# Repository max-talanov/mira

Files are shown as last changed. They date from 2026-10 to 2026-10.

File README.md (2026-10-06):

# MIRA

**MIRA is a research platform under development for experiments with memristor arrays and neuromorphic computing.**

The project aims to bring array control, an analog front end, digital processing, and software tools into a single system. It is intended for studying memristor readout and programming, vector–matrix multiplication (VMM), and spiking neuron models.

## Current status

**RevA** is currently in development. The repository contains two independent KiCad projects: the power schematics and an empty control project with local libraries.

Power development is focused on connection review, protection, sequencing, and monitoring. The control project is the starting point for drawing the MCU, FPGA, communications, and matrix circuits.

Schematics in this repository do not imply that the corresponding circuits have been built or validated in hardware.

## Repository contents

| Project | Current contents | Open in KiCad |
| --- | --- | --- |
| [MIRA_Power](hardware/MIRA_Power) | Power schematics, hierarchy, and local libraries | `hardware/MIRA_Power/MIRA_Power.kicad_pro` |
| [MIRA_Control](hardware/MIRA_Control) | One empty A4 schematic, an empty PCB, and local symbol, footprint, and STEP libraries | `hardware/MIRA_Control/MIRA_Control.kicad_pro` |

Each project has its own library tables and project-relative library paths. Keep its complete folder together.

The power project includes:

| File or directory | Purpose |
| --- | --- |
| `MIRA_Power.kicad_pro` | KiCad project file |
| `MIRA_Power.kicad_sch` | Top-level schematic and hierarchy navigation |
| `POWER_SYSTEM.kicad_sch` | Power system overview |
| `POWER_INPUT.kicad_sch` | Power input and primary protection |
| `PRIMARY_POWER.kicad_sch` | Primary power converters |
| `SECONDARY_POWER.kicad_sch` | Secondary power converters |
| `PROGRAM_SWITCHES.kicad_sch` | Programming voltage switching |
| `POWER_CONTROL.kicad_sch` | Power control and protection interlocks |
| `POWER_MONITOR.kicad_sch` | Voltage and current monitoring |
| `libraries/` | Local symbol, footprint, and 3D model libraries |

The power system is designed around an external **24 V DC supply**. It provides digital and analog power rails, controlled startup, rail monitoring, and fault shutdown.

## Planned architecture

- **Memristor array and analog front end:** readout, programming, and VMM operations.
- **FPGA:** array timing control and high-speed data transfer.
- **STM32:** neuron model computation and control tasks.
- **USB 3.0 and Ethernet:** communication with a host computer.
- **Mira Studio:** a desktop application for configuring experiments, controlling the device, visualizing data, and saving results.

These blocks describe the planned development direction. Their implementation status is reflected in the current project files.

## Opening the projects

1. Clone the repository:

   ```bash
   git clone https://github.com/max-talanov/mira.git
   ```

2. Open the required `.kicad_pro` file from the table above. On Linux:

   ```bash
   cd mira
   kicad hardware/MIRA_Power/MIRA_Power.kicad_pro
   # Or open the control project:
   kicad hardware/MIRA_Control/MIRA_Control.kicad_pro
   ```

3. In `MIRA_Power`, use the schematic hierarchy to navigate between blocks. In `MIRA_Control`, start with the empty A4 sheet and add circuits as development progresses.

Keep the directory structure intact. The `sym-lib-table` and `fp-lib-table` files are stored alongside the project and reference its local libraries.

## Versioning

**RevA** identifies the hardware revision. Git tags such as `v0.1.0` mark development milestones in the repository history.

| Tag | Milestone |
| --- | --- |
| `v0.1.0` | Initial KiCad project and local library import |
| `v0.2.0` | Separate Power and empty Control projects, with updated repository documentation |

Use commits for routine edits and annotated tags for milestones. Keep published tags on their original commits. A new repository tag does not change the hardware revision or indicate completed hardware validation.

See [CHANGELOG.md](CHANGELOG.md), the [commit history](https://github.com/max-talanov/mira/commits/main), and the [tag list](https://github.com/max-talanov/mira/tags).

## Licenses and attribution

See [LICENSE](LICENSE) and the third-party library and model notices included under each project's `libraries/` directory. Keep those notices with the corresponding assets.

## Next steps

- Verify electrical connections and coordinate protection thresholds with load requirements.
- Draw and review the control and matrix circuits in `MIRA_Control`.
- Complete consistent schematic formatting and descriptions.
- Review component suitability and availability.
- Prepare component placement and PCB routing.

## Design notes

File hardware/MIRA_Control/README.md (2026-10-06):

# MIRA Control — empty KiCad project

Open **MIRA_Control.kicad_pro**. The project contains one blank A4 schematic and an empty PCB. It is intended for building MIRA Control Rev.A from scratch.

## Local library

Keep the complete folder together. Both library tables use the nickname `MIRA_RevA` and project-relative paths. No global library installation is required.

- 151 unique symbols: the original ICs, connectors and passive variants, plus 16 ready-to-place 0201 capacitor/resistor variants with Value, MPN, Manufacturer, Footprint, Datasheet and Description filled in. One identical 10k resistor entry was removed.
- 48 local footprints and 48 local STEP models, including C/R 0201.
- 0201 body size is 0.6 x 0.3 mm; local copper-pad gap is 0.22 mm.
- The generic Capacitor and Resistor symbols remain generic; select the appropriate filled variant when an ordering part is known. Larger and precision variants are retained for suitable circuits.

`docs/PASSIVES_0201.csv` lists the 16 new 0201 choices. The 100n 16V part is X7S; retain the original X7R/other suitable variant when capacitance tolerance is important, including USB coupling. `docs/models/` contains model source and license records.

## Project settings

Minimum copper clearance and Default netclass clearance are 0.2 mm. Existing generic board defaults are retained; no finished layer stack, outline, net assignments or circuit is defined.

## Repository placement

Place the complete **MIRA_Control/** folder under **hardware/** in the existing MIRA repository. Commit the .kicad_pro, .kicad_sch, .kicad_pcb, both library tables, libraries/ and docs/ together. The included .gitignore excludes local preferences, locks, autosave and backup files.

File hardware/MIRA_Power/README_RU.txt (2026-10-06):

MIRA — пустой проект с готовыми библиотеками
=====================================================

Начало работы
1. Распакуйте ВЕСЬ архив в отдельную папку.
2. В менеджере KiCad откройте MIRA.kicad_pro.
3. Откройте пустую схему MIRA.kicad_sch из менеджера проекта.
4. В другом окне откройте исходный MIRA_RevA_Annotated.
5. Копируйте нужные компоненты вместе с проводами, метками и пояснениями
   через Ctrl+C и Ctrl+V в новый проект. Создавайте дочерние листы по мере
   необходимости. Для сохранения или изменения обозначений используйте
   Edit > Paste Special (Ctrl+Shift+V) и выбирайте нужный вариант аннотации.

Состав
- Пустая схема и пустая плата, проект MIRA.
- Полная библиотека MIRA_RevA из последнего Annotated: символы,
  47 посадочных мест и все поставлявшиеся с проектом локальные 3D-модели.
- Локальные полные библиотеки Device, power и Jumper. Семь используемых
  стандартных символов совпадают с их определениями в исходной схеме.
- Готовые sym-lib-table и fp-lib-table, пути относительно папки проекта.
- Настройки черчения, ERC, классов цепей и сетки соединений исходного проекта.

Не требуется добавлять библиотеку вручную или менять глобальные настройки
KiCad. Имя библиотеки MIRA_RevA сохранено, чтобы ссылки вставленных символов
и посадочных мест продолжали работать. Новый проект использует собственную
копию библиотеки: изменения в ней не изменяют исходный Annotated.

Важные детали переноса
- Не переносите только файл .kicad_pro: папка libraries и обе таблицы должны
  оставаться рядом с ним. Саму папку проекта можно перемещать целиком.
- Для монтажа электрических соединений выбирайте в редакторе сетку 50 mil
  (1.27 мм). Настройка сетки соединений уже такая; текущая отображаемая сетка
  редактора относится к личным настройкам KiCad.
- Новый лист достаточно широкий, чтобы вставить целый лист Annotated
  вместе с правой панелью описания. Формат можно изменить в Page Settings.
- Когда копируете только содержимое листа, выделяйте именно компоненты,
  провода и текст на нём. Копирование рамки дочернего листа на обзорной схеме
  переносит ссылку на файл листа: сам этот файл также нужен новому проекту.
- Стандартные 3D-модели нескольких 0603 посадочных мест используют пакет
  3D-моделей KiCad, как в исходном Annotated. На символы и вставку схем
  это не влияет.

Формат проекта: KiCad 10, как в последнем MIRA_RevA_Annotated.
Проверка: все использованные в исходных 46 листах символы и посадочные места
разрешаются в подключённых библиотеках; проект не содержит старой иерархии,
обозначений компонентов, замков или состояния навигации.

Справка KiCad:
https://docs.kicad.org/10.0/en/eeschema/eeschema.html

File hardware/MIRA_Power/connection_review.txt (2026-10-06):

MIRA Rev.A — Power Control connection review
2026-10-05

Scope and validation

Reviewed POWER_CONTROL and all ten attached child schematics, 2400 through
3300. The electrical graph was reconstructed from native embedded symbol
pins, wires, junctions, scoped local labels and global labels. KiCad instance
rotation and screen-axis mirroring were included. Manufacturer pinouts and
logic functions were checked against the documents listed below.

Four confirmed connection defects were corrected. A separate final comparison
verified every original pin position, symbol orientation, pin identity and net
partition against the source plus the four explicit repairs. The parent UUID,
all ten child sheet UUIDs, filenames and hierarchy paths were preserved.
The existing MIRA_RevA embedded definitions were retained. R3203 reuses the
existing Panasonic 10 kOhm resistor definition and footprint.

The English guides use the same five headings on every child sheet. The parent
has an individual description of every block and a logical interconnection
overview. Blue annotations distinguish circuit groups. The parent graphics
show signal relationships; the leaf global nets provide the actual electrical
connections. Preview images are approximate renders of native geometry rather
than KiCad plots. All eleven previews were visually inspected and annotations
checked against their drawing frames.

Native KiCad ERC, simulation, firmware validation, PCB checks and bench tests
were not performed. Missing monitor circuits limit whole-system conclusions.

Confirmed defects and completed repairs

1. 2600: U2601 pin 8 (global protection AND output) was unconnected, as was
   U2603 pin 1 (global permit asynchronous clear). Added the local
   GLOBAL_CLEAR_N connection between them. A LOW protection condition now
   reaches the global latch clear instead of leaving that input floating.

2. 2600: U2602 pin 8 (matrix readiness AND output) and U2603 pin 13 (matrix
   permit asynchronous clear) were unconnected. Added MATRIX_CLEAR_N between
   them. These local labels are on one sheet and do not change other nets.

3. 3100: U3103 pin 6 was globally labeled ALL_RAILS_PG. This joined it to
   the push-pull U3018 pin 6 output on 3000 and left the existing
   ALL_COMMANDS_ON input on U2602 pin 4 without its intended driver.
   Renamed the 3100 output to ALL_COMMANDS_ON. Its four local groups were
   renamed CMD_GROUP_0 through CMD_GROUP_3 and the copied hidden logic
   metadata was updated to match the actual CMD inputs.

4. 3200: U3201 pin 2 is open collector, but OC_OK_N had no external pull-up
   in any available schematic. Added R3203 = 10 kOhm from OC_OK_N to AON.
   At AON = 3.28 V its approximate fault sink current is 0.328 mA. The
   comparator output, resistor branch and global label share one continuous
   wire with a visible junction. A firmware-selected internal pull-up is not
   required to establish the released hardware level during MCU reset.

Documentation correction: J2502 now reads HOST MANUAL RESET CONTACT because
it connects to the host supervisor MR input. Its electrical pins did not move.
Several label/field positions were adjusted solely for legibility.

Verified circuit relationships

2400 — Dedicated power sequencer
U2401 is STM32G0B1RBT6, GP LQFP64. Its embedded supply and GPIO pin mapping
matches the GP part, including PD8/PD9 at pins 40/41. USART3 AF0 can use
these UART pins. PA0/PA1/PA2/PA3 receive ADC_I/ADC_V/ADC_VTT/PROG_V_P15.
Permits and externally driven status signals must be firmware inputs; enable,
arm and kill requests must initialize safely. Use internal clocking because
PF0 drives EN_REQ_USB. Keep NRST and SWD enabled and VREFBUF disabled while
VREF+ is tied to AON. FPGA matrix timing and STM32H745 neuron computation
remain outside this power sequencer.

2500 — Independent supervision
U2501 uses AON; U2502 uses SYS3V3. Both have SET1 HIGH and CWD unconnected:
watchdog timeout is 1.60 s nominal (1.36–1.84 s specified). Falling WDI edges
service the timers. Reset release delay and WDO LOW pulse are 200 ms nominal.
D2501 common-anode BAT54A correctly combines AON_RESET_N and PM_WDO_N into
PM_RESET_N. No diode rotation was needed. Host watchdog expiry inhibits the
matrix but does not locally combine WDO into the host RESET output.

2600 — Hardware permission and fault memory
The restored clear chains implement these conditions (AND of every item):

GLOBAL_CLEAR_N:
  AON_RESET_N, PM_WDO_N, PG_INPUT, FLT_INPUT_N, OC_OK_N,
  global stop/kill healthy node, PM_RESET_N.

MATRIX_CLEAR_N:
  GLOBAL_PWR_PERMIT, ALL_RAILS_PG, ALL_COMMANDS_ON, HOST_WDO_N,
  HOST_RESET_N, matrix stop/kill healthy node.

U2603 D inputs are HIGH and presets inactive. A rising arm edge can set a
permit only while its clear is HIGH. Any LOW clear asynchronously removes
that permit. Recovery alone does not re-arm. A global fault also removes the
matrix condition. Stops are CLOSE TO TRIP; an open cable is not detected.
Startup AON reset and clean arm timing still require system verification.

2700 / 2800 — Fifteen qualified enable commands
All eight primary and seven auxiliary channels use:
  CMD_x = EN_REQ_x AND GLOBAL_PWR_PERMIT.
Request and command pull-downs are present. The auxiliary spare gate has
grounded inputs and an NC output. Clearing the global permit suppresses all
commands independently of requests. Converter shutdown and discharge times
belong to their connected rail circuits.

2900 — Four analog readiness channels
Outputs PG_USB, PG_ANA, PG_P15 and PG_N15 have 10 kOhm AON pull-ups.
For AON = 3.28 V, the reference thresholds at the MON inputs are:
  MON_V_USB:   2.2313 V
  MON_V_ANA6:  2.6885 V
  MON_V_P15:   2.3597 V
  MON_V_N15:   1.3120 V
C2901–C2904 filter REFERENCES, with nominal time constants approximately
32, 18, 28 and 60 us. They do not filter the MON inputs or specify a fixed
power-good qualification delay. No analog feedback hysteresis is drawn.
Actual rail thresholds require the missing monitor scaling and polarity.

3000 / 3100 — Separate readiness and command aggregates
3000 ANDs fifteen measured PG/PGR signals into ALL_RAILS_PG.
3100 ANDs fifteen qualified CMD signals into ALL_COMMANDS_ON.
Each corrected global has one explicit push-pull driver. The local group
labels on the two sheets are independent. Global startup permission does
not depend on switched-rail readiness, allowing startup without a logical
deadlock. Matrix permission requires both aggregates; intentionally disabling
any included rail prevents matrix authorization. Neither tree contains a
timer or latch.

3200 — Negative-current check
Reference = AON x 10 / 57 = 0.57544 V at AON = 3.28 V.
C3201 filters this reference; (47 kOhm || 10 kOhm) x 10 nF = 82.46 us.
OC_I_N15 above the reference pulls OC_OK_N LOW and clears the global permit.
The conditioned current-sense producer is missing from the supplied scope,
so a trip current in amperes cannot be calculated or validated.

3300 — Debug and host interface
J3301: 1 AON reference, 2 GND, 3 SWDIO, 4 SWCLK, 5 PM_RESET_N.
J3302: 1 SYS3V3 reference, 2/9/10 GND, 3 buffered PM UART TX,
4 HOST_UART_TX, 5 HOST_WDI, 6 buffered MATRIX_PERMIT,
7 buffered ALL_RAILS_PG, 8 buffered GLOBAL_PWR_PERMIT.
HOST_RESET_N is not on J3302. U3301 supplies the four host-facing outputs
from SYS3V3 and supports partial power down. Host receive is pulled LOW
when undriven; firmware must handle this UART break/off condition.
R3304/C3301 form the nominal 10 us VTT ADC filter, with BAT54S rail clamps.

Remaining integration checks

- No producer for OC_I_N15 or MON_V_USB/ANA6/P15/N15 exists in the available
  native schematics. Do not attach raw negative voltage to the AON inputs.
  Restore or supply the documented conditioning circuits before relying on
  these protections. Current gain/offset and real rail thresholds are unknown.
- ADC_I/ADC_V and the telemetry multiplexer continue to unprovided circuitry.
  The available file named 1200_POWER_MONITOR contains a CORE regulator,
  not the required monitor/multiplexer. Do not infer its function from its name.
- SYS3V3 does have a producer on the earlier 700_SYS_3V3 sheet. The host
  supervisor output below its POR level is undefined; AON pull-ups can make
  off-rail status look HIGH. Independent measured readiness must inhibit arm.
- Confirm the external host supplies HOST_WDI and receives reset through a
  separately defined path. Verify firmware recovery policy for host expiry.
- Verify all fifteen rails are intentionally required for matrix operations,
  ADC input settling and clamp injection, reset LOW margins, AON startup,
  comparator noise, arm/clear timing and actual shutdown on hardware.

Manufacturer references

ST STM32G0B1 GP pinout and alternate functions:
https://www.st.com/resource/en/datasheet/stm32g0b1ve.pdf
TI TPS3851 pinout, output behavior and watchdog settings:
https://www.ti.com/lit/ds/symlink/tps3851.pdf
TI SN74HC74 clear/preset and latch behavior:
https://www.ti.com/lit/ds/symlink/sn74hc74.pdf
TI SN74HCS21 AND gates and Schmitt inputs:
https://www.ti.com/lit/ds/symlink/sn74hcs21.pdf
TI TLV1704 comparator pinout and output pull-up requirement:
https://www.ti.com/lit/ds/symlink/tlv1704.pdf
Nexperia 74LVC125A buffering and partial power down:
https://assets.nexperia.com/documents/data-sheet/74LVC125A.pdf

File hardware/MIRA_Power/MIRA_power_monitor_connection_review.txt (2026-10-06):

MIRA Rev.A — Power Monitor connection review
2026-10-05

Scope and validation

Reviewed POWER_MONITOR and its seven active child sheets, 3400 through 4000.
Connections were reconstructed from the native embedded symbol definitions,
rotation/mirror-aware pin geometry, wires, junctions and scoped labels. The
monitor signals were traced through the previously reviewed rail, programming
and Power Control sheets. Manufacturer pinouts and functions were checked.

An independent final comparison verified 242 symbol identities and all pin
positions and net partitions. Wires, labels, junctions and no-connect markers
are unchanged. The sole component change is R3609, described below. Parent and
child UUIDs, hierarchy paths, filenames and MIRA_RevA definitions are preserved.

The overall sheet contains an E4-style logical interconnection overview and
individual descriptions of all seven blocks. The graphical collector denotes
16 separate signal pairs; it is not an electrical short or a KiCad bus. Actual
connections remain the global nets in the native leaves. The leaf guides use
the same five headings. Blue notes distinguish repeated circuits. All eight
previews were visually checked and all new text fits the existing drawing
frames. Previews are approximate renders of native geometry, not KiCad plots.

The empty, unreferenced 3600_MONITOR_INPUT_AON_USB_SYS attachment shares the
3500 root UUID. It was left unchanged and excluded from the active bundle.

Native KiCad ERC, simulation, firmware/PCB validation and bench measurements
were not performed. This review confirms the stated schematic relationships,
not validated whole-system protection or shutdown timing.

Confirmed defect and completed correction

3600: R3609 = 10 kOhm and R3610 = 10 kOhm demanded MON_V_P15 = 7.5 V
at a 15 V rail, continuously loading the AON clamp and corrupting telemetry.
R3609 is now 47 kOhm. MON_V_P15 = P15 / 5.7, giving 2.6316 V at 15 V.
The native library ID, value, MPN and description now consistently identify
Panasonic ERJ1GNF4702C; the existing 0201 footprint and pin locations remain.
This scale also gives a nominal PG_P15 threshold of 13.4504 V at AON = 3.28 V.

Verified current sensing and nominal thresholds

The positive-rail INA301A1 channels have gain 20 V/V. Their 10 kOhm LIMIT
resistors set a nominal 0.800 V threshold from the nominal 80 uA source.
Grounded RESET selects transparent alerts. Current filters follow OUT and
do not delay the internal overcurrent comparator. Nominal values below omit
amplifier, limit-source, shunt, resistor and temperature errors.

Rail        External shunt       Current scale     Nominal trip
INPUT       stated 20 mOhm       0.400 V/A         no local alert
AON         R503, 100 mOhm       2.000 V/A         0.400 A
USB         R604, 50 mOhm        1.000 V/A         0.800 A
SYS         R705, 10 mOhm        0.200 V/A         4.000 A
FPGA        R805, 10 mOhm        0.200 V/A         4.000 A
ANA6        R904, 50 mOhm        1.000 V/A         0.800 A
P15         R1004, 100 mOhm      2.000 V/A         0.400 A
N15         R1107, 100 mOhm      2.000 V/A         0.288 A at AON 3.28 V
CORE        R1205, 2 mOhm        0.040 V/A        20.000 A
AUX18       R1305, 20 mOhm       0.400 V/A         2.000 A
AUX25       R1405, 20 mOhm       0.400 V/A         2.000 A
IO33        R1505, 20 mOhm       0.400 V/A         2.000 A
DDR         R1605, 10 mOhm       0.200 V/A         4.000 A
PHY         R1705, 20 mOhm       0.400 V/A         2.000 A
ANA5        R1905, 50 mOhm       1.000 V/A         0.800 A
ANA33       R2005, 50 mOhm       1.000 V/A         0.800 A

U3501 INA293 supplies input-current telemetry. Its IN+ is BUS24_PRE_SHUNT
and IN- is BUS24. The current 400_INPUT_FILTER_SENSE leaf was not supplied.
The stated 20 mOhm input shunt is corroborated by the historical input-filter
reference (R203 between those same nets), but its current reference/value and
the PG_INPUT producer still require the actual current input subsystem.
All fifteen other shunt polarities and net names match the supplied rail sheets.

3400: U3401 OPA2991 uses AON for V+ and N15_RAW for V-. Channel A gives
20 x (N15 - N15_RAW), a positive return-current signal. MON_I_N15 uses a
10 kOhm/100 nF filter; OC_I_N15 uses a separate 10 kOhm branch without that
telemetry capacitor. Channel B gives MON_V_N15 = -0.1 x N15; -15 V becomes
+1.50 V. Both telemetry time constants are nominally 1 ms. BAT54S clamp
polarities are correct. The four differential gain-network resistors specify
0.1% tolerance. Their resistor-only worst-case common-mode leakage at -15 V
is approximately +/-57 mV, or +/-28.6 mA equivalent; the complete error budget
must also include amplifier, shunt, comparator, reference and layout errors.

Voltage scales and hardware power-good

INPUT uses (75k + 75k) / 10k, giving rail/16. P15 now uses rail/5.7.
N15 uses -rail/10. All other selected voltage channels use rail/2.
The positive current filters have nominal RC = 10 us. The half-scale voltage
filters have RC = 50 us; INPUT is 93.75 us and repaired P15 is 82.46 us.

MON_V_USB, MON_V_ANA6, MON_V_P15 and MON_V_N15 directly feed the four
2900 comparator channels as well as telemetry. At AON = 3.28 V their nominal
physical rail readiness thresholds are USB 4.4626 V, ANA6 5.3770 V,
P15 13.4504 V and |N15| 13.1200 V. These follow AON and upstream ratios;
they are not precision absolute thresholds. There is no local hysteresis.

Shared overcurrent and interlocks

Fourteen INA301 open-drain ALERT outputs and the 3200 negative-current
comparator share OC_OK_N. A fault pulls it LOW and reaches the hardware permit
clear on 2600 independently of telemetry scanning. It also reaches 2400 PA12.
The 3200 reference is AON x 10/57 = 0.57544 V at 3.28 V. With the 3400
2 V/A scale, its nominal trip is 0.28772 A. The comparator reference RC is
82.46 us; this is not a specified complete fault-to-shutdown delay.

R4008 already provides 10 kOhm to AON. Retained R3203 on the reviewed Power
Control sheet adds a parallel 10 kOhm, making the assembled pullup 5 kOhm
and approximately 0.656 mA fault sink current at AON = 3.28 V. These pullups
are compatible; OC_OK_N does not depend on a firmware internal pullup.

Verified paired telemetry channel map

Both selectors use this exact order. A0 is the least significant address bit.
The pin column is the physical channel pin on each CD74HC4067.

Channel  A3..A0  Pin  Current net      Voltage net      Source sheet
      0  0000     9   MON_I_INPUT      MON_V_INPUT      3500
      1  0001     8   MON_I_AON        MON_V_AON        3500
      2  0010     7   MON_I_USB        MON_V_USB        3500
      3  0011     6   MON_I_SYS        MON_V_SYS        3500
      4  0100     5   MON_I_FPGA       MON_V_FPGA       3600
      5  0101     4   MON_I_ANA6       MON_V_ANA6       3600
      6  0110     3   MON_I_P15        MON_V_P15        3600
      7  0111     2   MON_I_N15        MON_V_N15        3400
      8  1000    23   MON_I_CORE       MON_V_CORE       3700
      9  1001    22   MON_I_AUX18      MON_V_AUX18      3700
     10  1010    21   MON_I_AUX25      MON_V_AUX25      3700
     11  1011    20   MON_I_IO33       MON_V_IO33       3700
     12  1100    19   MON_I_DDR        MON_V_DDR        3800
     13  1101    18   MON_I_PHY        MON_V_PHY        3800
     14  1110    17   MON_I_ANA5       MON_V_ANA5       3800
     15  1111    16   MON_I_ANA33      MON_V_ANA33      3800

3900: Both devices share MUX_A0..A3 and MUX_DISABLE. HIGH disconnects
both COM outputs; LOW enables the chosen current/voltage pair. R4001-R4004
hold address zero and R4007 holds disable HIGH at controller reset. Disabled
COM inputs float, so the buffer/ADC outputs are not valid measurements.

4000: U4001A follows MUX_I_COM; output pin 1 feeds back to IN- pin 2.
U4001B follows MUX_V_COM; output pin 7 feeds back to IN- pin 6. R4005/C4002
and R4006/C4003 use 100 Ohm/1 nF (0.10 us nominal RC). Feedback is taken
before these resistors. ADC_I reaches 2400 PA0/pin 17 and ADC_V PA1/pin 18.
MUX_A0/A1/A2/A3/DISABLE reach PB15/PA8/PA9/PC6/PC7 respectively.

Firmware should disable, update the address, enable and wait for the source,
selector, buffer and ADC acquisition to settle before accepting samples.
The 0.10 us output RC alone does not define this wait. Current and voltage
are a selected pair; the STM32 ADC samples them sequentially. ADC_VTT is a
separate 3300-to-PA2 route; PROG_V_P15 is a separate 2300-to-PA3 route.

Remaining design decisions and verification

- CORE nominal trip 20 A exceeds the TPS568215 8 A converter rating. DDR
  nominal trip 4 A exceeds the TPS62130A 3 A converter rating. The converters'
  own limits may act first. Establish load, inrush and thermal budgets, then
  coordinate external trips with the regulator limits; their resistor values
  were retained rather than selecting an unsupported load budget.
- ANA5 current includes its downstream ANA3V3 load. Coordinate these nested
  thresholds instead of treating them as independent available load budgets.
- Confirm the current input-filter/eFuse leaves, PG_INPUT/FLT_INPUT_N and
  input shunt identity before claiming complete startup-path validation.
- Qualify telemetry and arm logic during AON loss, rail ramp/discharge and
  negative-supply transitions. Check clamp injection and all analog input
  operating limits when adjacent supplies are absent.
- Verify Kelvin shunt routing, gain/offset calibration, comparator noise,
  safe firmware pin defaults, ADC acquisition and actual shutdown on hardware.

Manufacturer references

TI OPA2991: https://www.ti.com/lit/ds/symlink/opa2991.pdf
TI INA301: https://www.ti.com/lit/ds/symlink/ina301.pdf
TI INA293: https://www.ti.com/lit/ds/symlink/ina293.pdf
TI CD74HC4067: https://www.ti.com/lit/ds/symlink/cd74hc4067.pdf
TI TLV9002: https://www.ti.com/lit/ds/symlink/tlv9002.pdf
TI TLV1704: https://www.ti.com/lit/ds/symlink/tlv1704.pdf
TI TPS568215: https://www.ti.com/lit/ds/symlink/tps568215.pdf
TI TPS62130A: https://www.ti.com/lit/ds/symlink/tps62130a.pdf
ST STM32G0B1: https://www.st.com/resource/en/datasheet/stm32g0b1ve.pdf

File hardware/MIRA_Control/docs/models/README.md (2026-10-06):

# Local 3D models

All 48 footprints reference models through `${KIPRJMOD}/libraries/MIRA_RevA.3dshapes/`. The STEP files and source/licensing records in model_manifest.json are copied from the updated MIRA Control Rev.A library.

Six models are nominal drawing models: HD3SS3220, Micron DDR3L FBGA96, SiTime SiT9121, Winbond WSON8 and the two new 0201 passives. They are package envelopes rather than manufacturer-certified tolerance models. The two 0201 models are original CC0 geometry; earlier models retain their documented licensing.

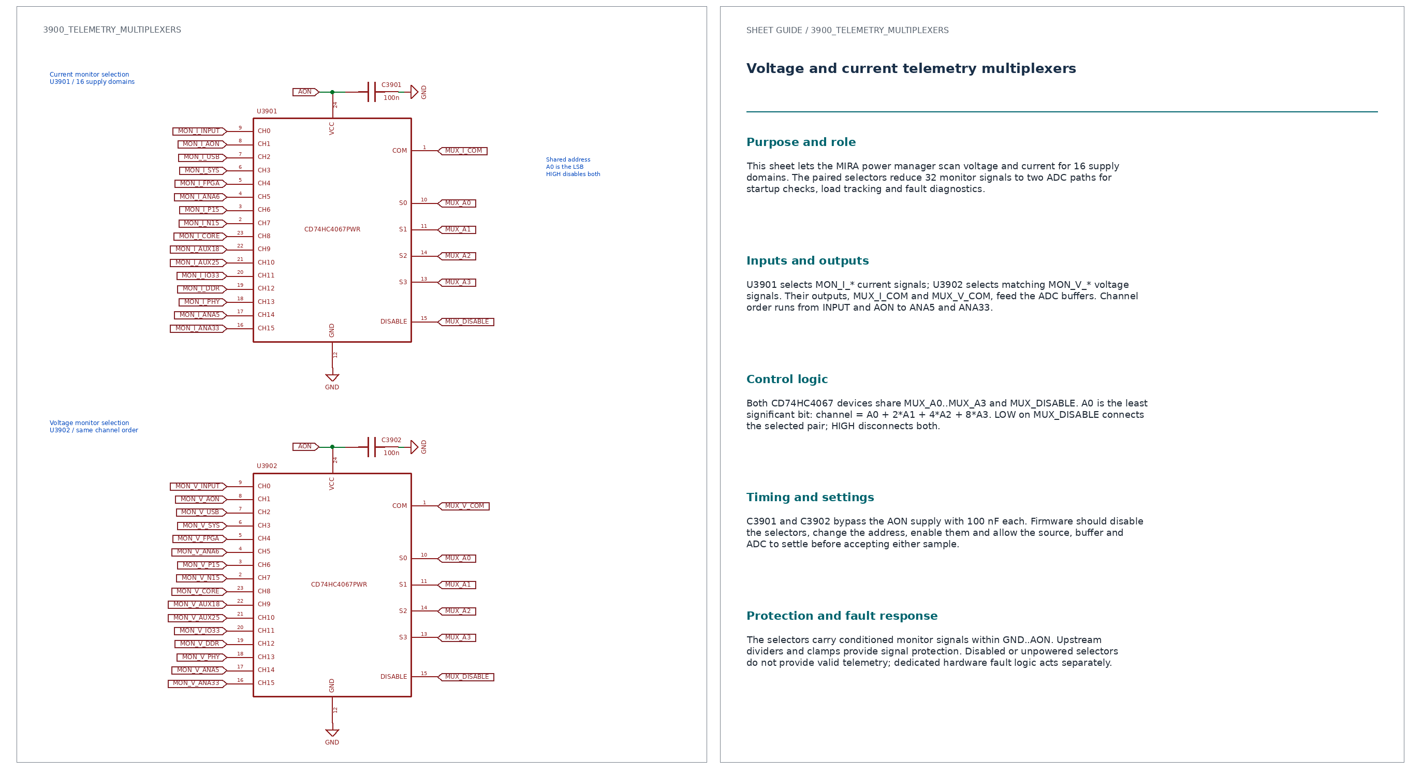
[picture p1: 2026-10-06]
hardware/MIRA_Power/3900_TELEMETRY_MULTIPLEXERS_preview.png

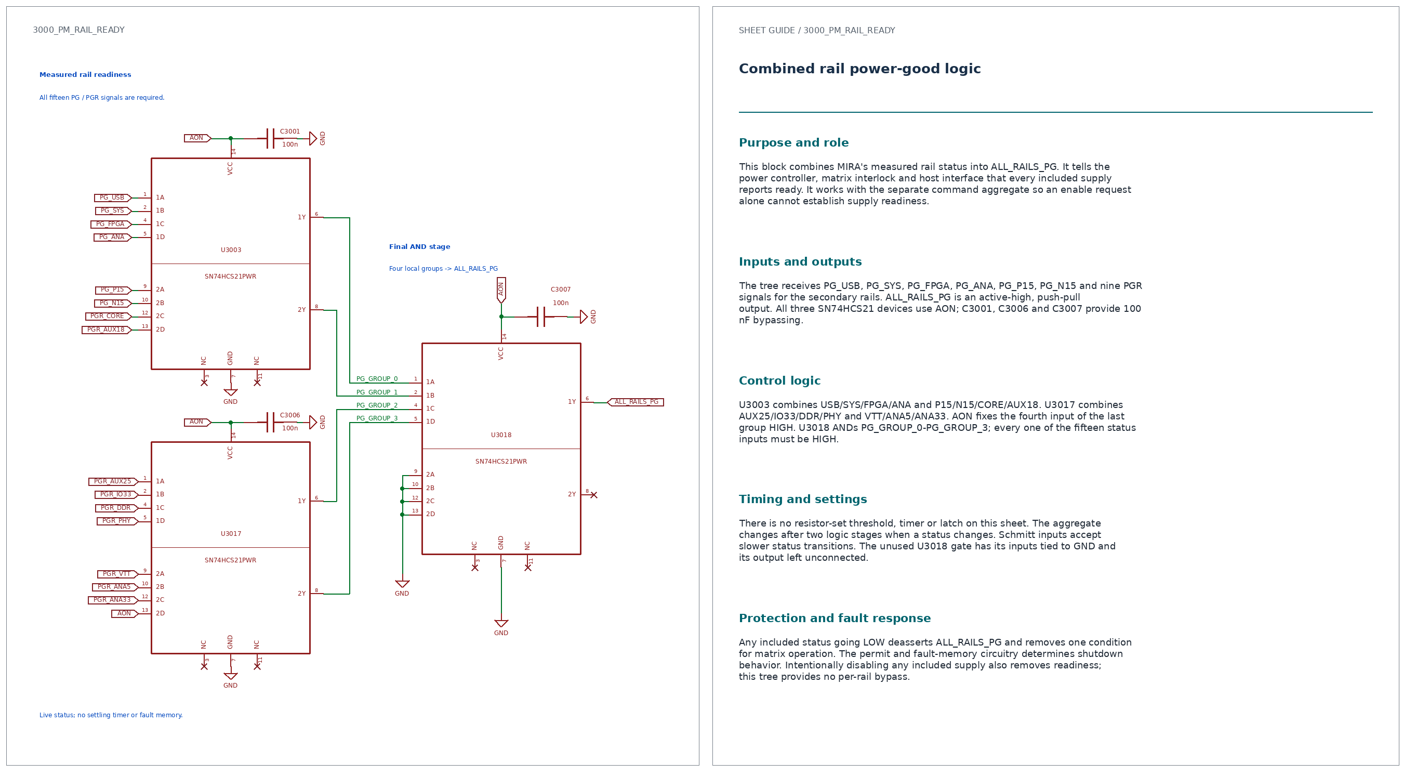
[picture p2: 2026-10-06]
hardware/MIRA_Power/3000_PM_RAIL_READY_preview.png

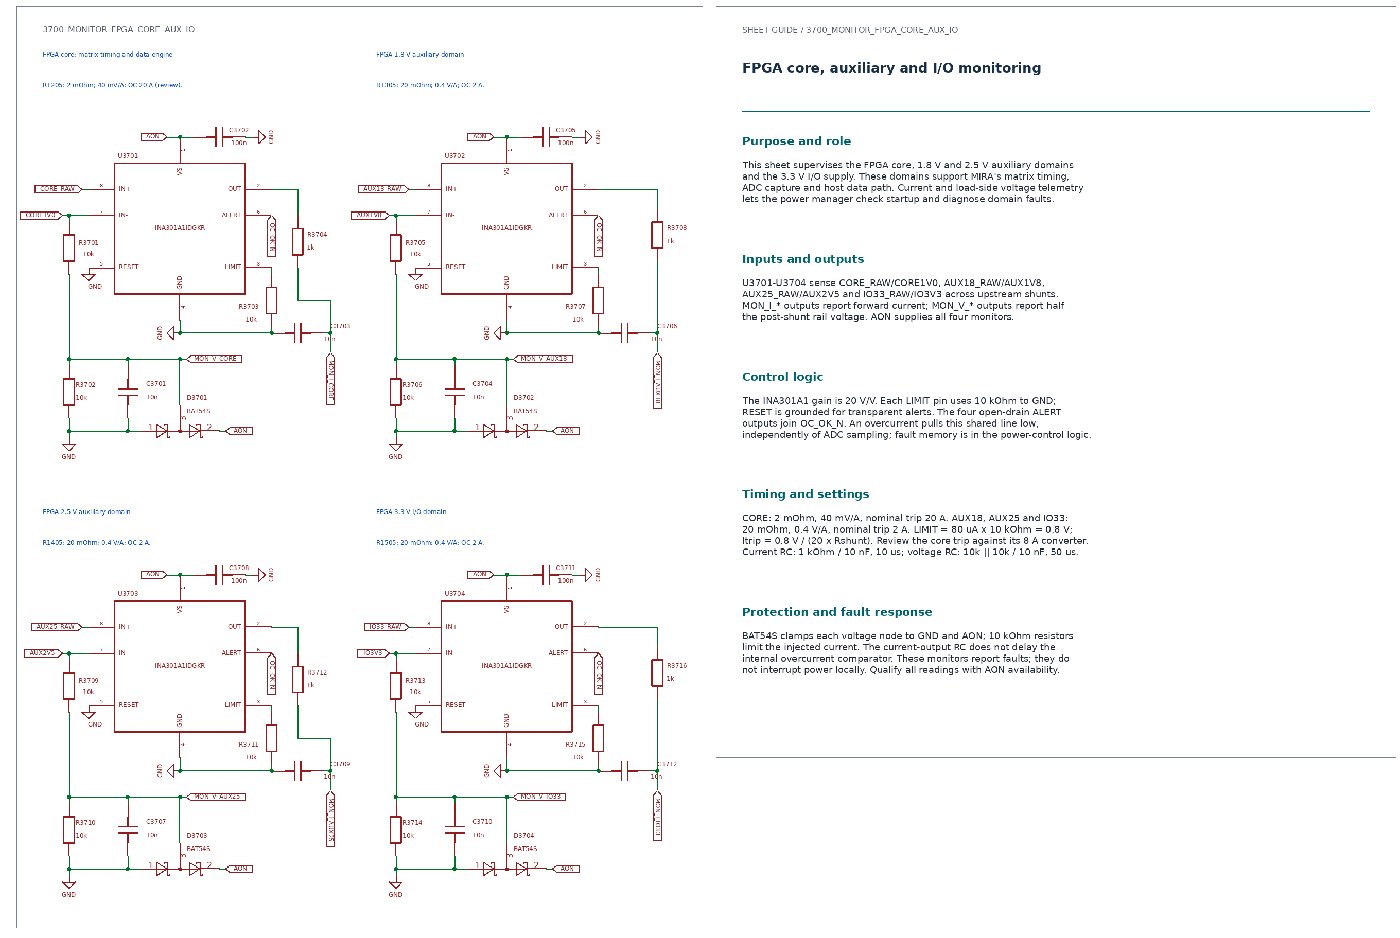
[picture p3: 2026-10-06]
hardware/MIRA_Power/3700_MONITOR_FPGA_CORE_AUX_IO_preview.png

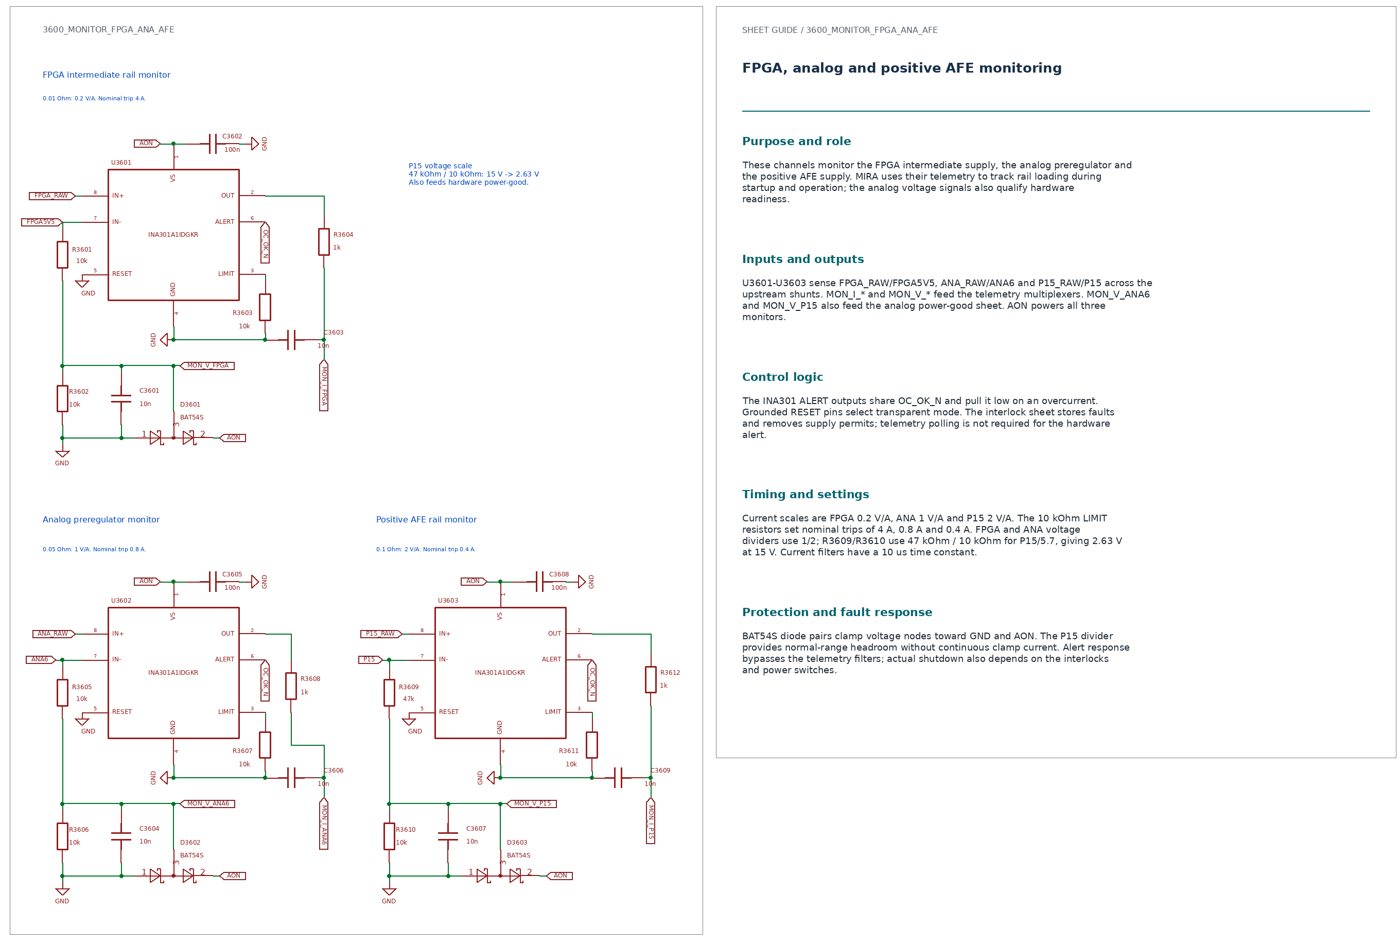
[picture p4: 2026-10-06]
hardware/MIRA_Power/3600_MONITOR_FPGA_ANA_AFE_preview.png

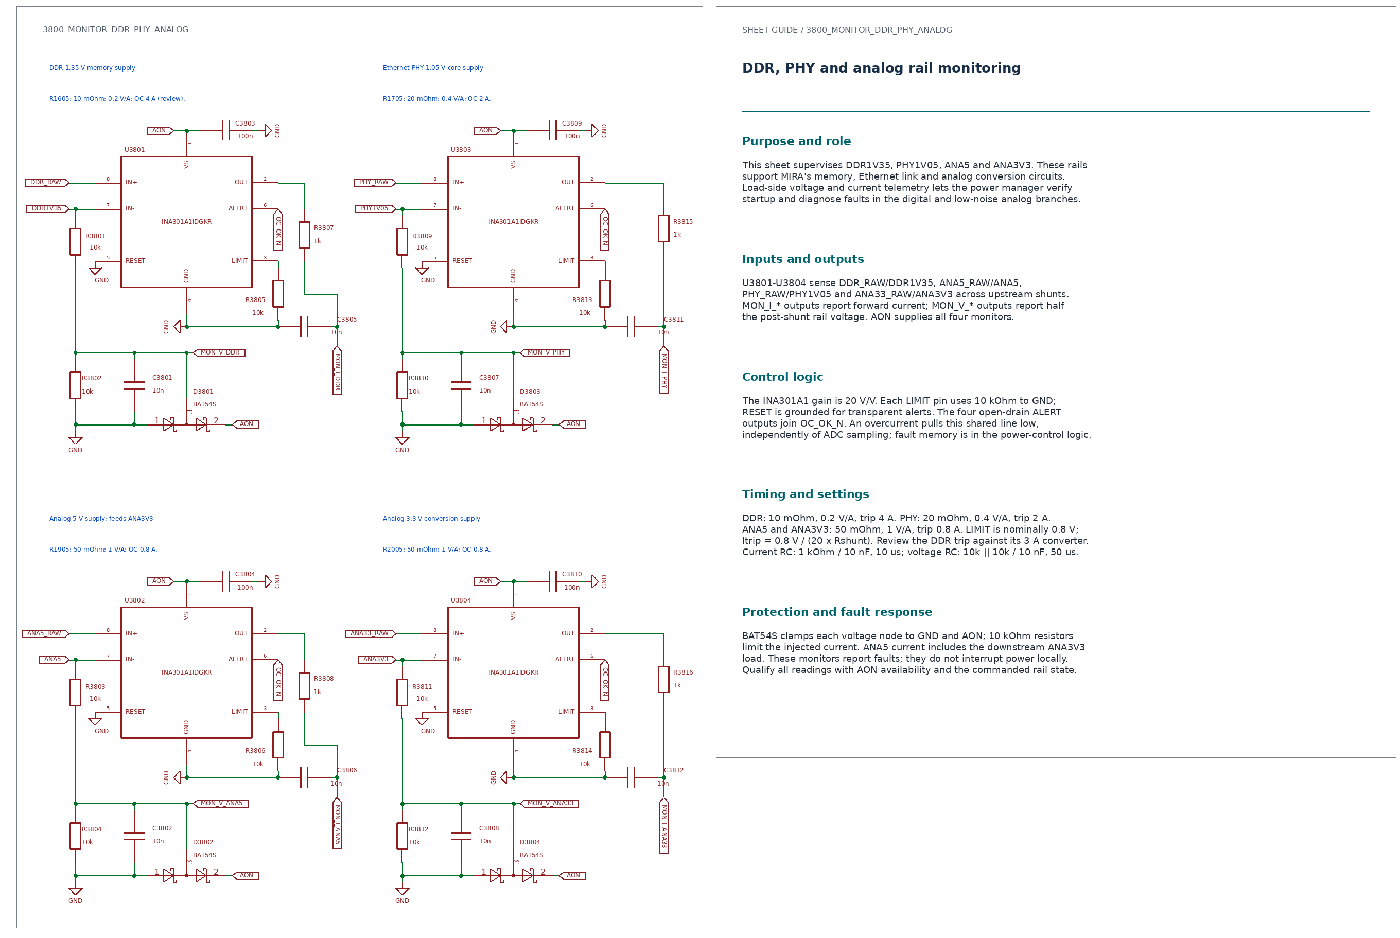
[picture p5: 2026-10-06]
hardware/MIRA_Power/3800_MONITOR_DDR_PHY_ANALOG_preview.png

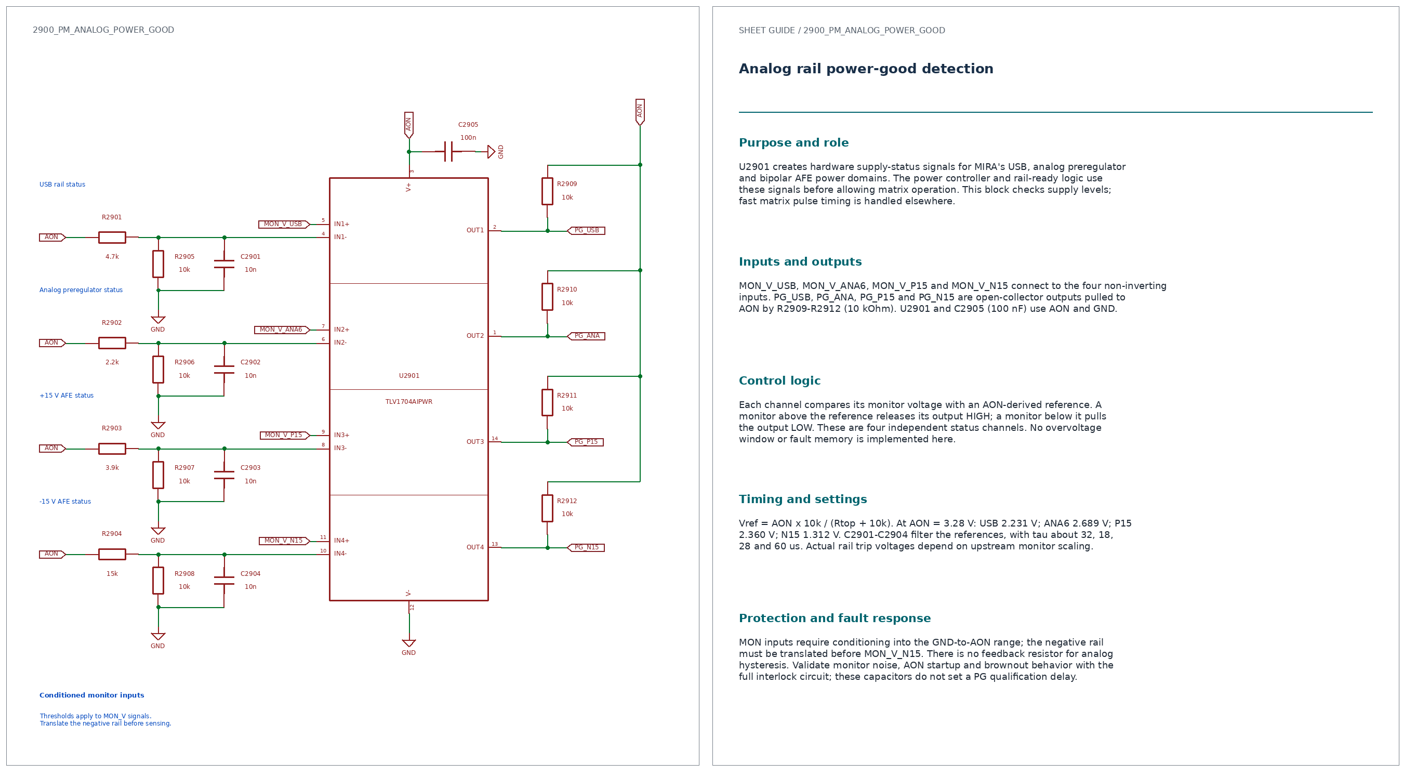
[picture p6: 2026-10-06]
hardware/MIRA_Power/2900_PM_ANALOG_POWER_GOOD_preview.png

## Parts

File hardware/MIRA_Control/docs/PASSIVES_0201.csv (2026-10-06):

Symbol | Value | MPN | Manufacturer | Footprint | Datasheet | Description
C_12p_50V_C0G_0201 | 12p | C0603C0G1H120J030BA | TDK | MIRA_RevA:C_0201_0603Metric | https://product.tdk.com/en/search/capacitor/ceramic/mlcc/info?part_no=C0603C0G1H120J030BA | 12 pF, 50 V, C0G, +/-5%, 0201 (0603 metric), crystal load capacitor
C_22p_50V_C0G_0201 | 22p | C0603C0G1H220J030BA | TDK | MIRA_RevA:C_0201_0603Metric | https://product.tdk.com/en/search/capacitor/ceramic/mlcc/info?part_no=C0603C0G1H220J030BA | 22 pF, 50 V, C0G, +/-5%, 0201 (0603 metric), crystal load capacitor
C_100n_16V_X7S_0201 | 100n | C0603X7S1C104K030BB | TDK | MIRA_RevA:C_0201_0603Metric | https://product.tdk.com/en/search/capacitor/ceramic/mlcc/info?part_no=C0603X7S1C104K030BB | 100 nF, 16 V, X7S, +/-10%, 0201 (0603 metric), local bypass / AC coupling; temperature coefficient +/-22%
R_100k_1pct_0201 | 100k | RC0201FR-07100KL | Yageo | MIRA_RevA:R_0201_0603Metric | https://yageogroup.com/component-documentation/download/specsheet/RC0201FR-07100KL | 100k ohm, +/-1%, 50 mW at 70 C, 25 V max working, +/-200 ppm/C, 0201 (0603 metric)
R_100_1pct_0201 | 100 | RC0201FR-07100RL | Yageo | MIRA_RevA:R_0201_0603Metric | https://yageogroup.com/component-documentation/download/specsheet/RC0201FR-07100RL | 100 ohm, +/-1%, 50 mW at 70 C, 25 V max working, +/-200 ppm/C, 0201 (0603 metric)
R_10k_1pct_0201 | 10k | RC0201FR-0710KL | Yageo | MIRA_RevA:R_0201_0603Metric | https://yageogroup.com/component-documentation/download/specsheet/RC0201FR-0710KL | 10k ohm, +/-1%, 50 mW at 70 C, 25 V max working, +/-200 ppm/C, 0201 (0603 metric)
R_1k_1pct_0201 | 1k | RC0201FR-071KL | Yageo | MIRA_RevA:R_0201_0603Metric | https://yageogroup.com/component-documentation/download/specsheet/RC0201FR-071KL | 1k ohm, +/-1%, 50 mW at 70 C, 25 V max working, +/-200 ppm/C, 0201 (0603 metric)
R_1M_1pct_0201 | 1M | RC0201FR-071ML | Yageo | MIRA_RevA:R_0201_0603Metric | https://yageogroup.com/component-documentation/download/specsheet/RC0201FR-071ML | 1M ohm, +/-1%, 50 mW at 70 C, 25 V max working, +/-200 ppm/C, 0201 (0603 metric)
R_200k_1pct_0201 | 200k | RC0201FR-07200KL | Yageo | MIRA_RevA:R_0201_0603Metric | https://yageogroup.com/component-documentation/download/specsheet/RC0201FR-07200KL | 200k ohm, +/-1%, 50 mW at 70 C, 25 V max working, +/-200 ppm/C, 0201 (0603 metric)
R_20k_1pct_0201 | 20k | RC0201FR-0720KL | Yageo | MIRA_RevA:R_0201_0603Metric | https://yageogroup.com/component-documentation/download/specsheet/RC0201FR-0720KL | 20k ohm, +/-1%, 50 mW at 70 C, 25 V max working, +/-200 ppm/C, 0201 (0603 metric)
R_22_1pct_0201 | 22 | RC0201FR-0722RL | Yageo | MIRA_RevA:R_0201_0603Metric | https://yageogroup.com/component-documentation/download/specsheet/RC0201FR-0722RL | 22 ohm, +/-1%, 50 mW at 70 C, 25 V max working, +/-200 ppm/C, 0201 (0603 metric)
R_2p2k_1pct_0201 | 2.2k | RC0201FR-072K2L | Yageo | MIRA_RevA:R_0201_0603Metric | https://yageogroup.com/component-documentation/download/specsheet/RC0201FR-072K2L | 2.2k ohm, +/-1%, 50 mW at 70 C, 25 V max working, +/-200 ppm/C, 0201 (0603 metric)
R_33_1pct_0201 | 33 | RC0201FR-0733RL | Yageo | MIRA_RevA:R_0201_0603Metric | https://yageogroup.com/component-documentation/download/specsheet/RC0201FR-0733RL | 33 ohm, +/-1%, 50 mW at 70 C, 25 V max working, +/-200 ppm/C, 0201 (0603 metric)
R_47k_1pct_0201 | 47k | RC0201FR-0747KL | Yageo | MIRA_RevA:R_0201_0603Metric | https://yageogroup.com/component-documentation/download/specsheet/RC0201FR-0747KL | 47k ohm, +/-1%, 50 mW at 70 C, 25 V max working, +/-200 ppm/C, 0201 (0603 metric)
R_49p9_1pct_0201 | 49.9 | RC0201FR-0749R9L | Yageo | MIRA_RevA:R_0201_0603Metric | https://yageogroup.com/component-documentation/download/specsheet/RC0201FR-0749R9L | 49.9 ohm, +/-1%, 50 mW at 70 C, 25 V max working, +/-200 ppm/C, 0201 (0603 metric)
R_4p7k_1pct_0201 | 4.7k | RC0201FR-074K7L | Yageo | MIRA_RevA:R_0201_0603Metric | https://yageogroup.com/component-documentation/download/specsheet/RC0201FR-074K7L | 4.7k ohm, +/-1%, 50 mW at 70 C, 25 V max working, +/-200 ppm/C, 0201 (0603 metric)

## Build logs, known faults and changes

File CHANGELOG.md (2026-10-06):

# MIRA changelog

Repository milestones are separate from hardware revisions. Both projects currently use **RevA**.

## v0.2.0 — 2026-10-06

- Separate `hardware/MIRA_Power` and `hardware/MIRA_Control` projects.
- Replace the Control hierarchy scaffold with one empty A4 schematic and an empty PCB, retaining its local symbol, footprint, and STEP libraries.
- Update the root README with both projects, their current status, and opening instructions.
- Document milestone tags and retain `v0.1.0` on the original import.
- Add Git attributes for consistent KiCad text files and concise 3D model diffs.

This milestone describes repository organisation. Control circuitry, PCB routing, and hardware validation remain development work.

## v0.1.0 — 2026-10-06

- Import the MIRA RevA KiCad project and local libraries at commit `4b14a7e`.
- Mark the initial import with an annotated tag.

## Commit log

2026-10-06 Add MIRA RevA KiCad project and local libraries
    [1000_AFE_POSITIVE_15V.kicad_sch, 100_INPUT_CONNECTOR.kicad_sch, 1100_AFE_NEGATIVE_15V.kicad_sch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]
2026-10-06 Rename power board project to MIRA_Power
    [1000_AFE_POSITIVE_15V.kicad_sch, 100_INPUT_CONNECTOR.kicad_sch, 1100_AFE_NEGATIVE_15V.kicad_sch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]
2026-10-06 Update project references and README for MIRA_Power
    [1000_AFE_POSITIVE_15V.kicad_sch, 100_INPUT_CONNECTOR.kicad_sch, 1100_AFE_NEGATIVE_15V.kicad_sch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]
2026-10-06 Add MIRA Control RevA skeleton and local libraries
    [0010_EXTERNAL_SUPPLIES.kicad_sch, 0020_EXTERNAL_POWER_CONTROL.kicad_sch, 4100A_MCU_SUPPLY_BYPASS.kicad_sch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]
2026-10-06 Replace MIRA Control with empty KiCad project
    [0010_EXTERNAL_SUPPLIES.kicad_sch, 0020_EXTERNAL_POWER_CONTROL.kicad_sch, 4100A_MCU_SUPPLY_BYPASS.kicad_sch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]
2026-10-06 Replace MIRA Control with empty project and updated 0201 library
    [MIRA_Control.kicad_sch, PASSIVES_0201.csv]
2026-10-06 Update MIRA Control schematics
    [100_MCU_POWER_CORE.kicad_sch, 200_MCU_FMC_INTERFACE.kicad_sch, 300_MCU_SERIAL_CONTROL.kicad_sch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]
2026-10-27 Save MIRA Control and Power baseline before PCB preparation
2026-10-27 Document Power-Control interboard review and close checklist item
2026-10-27 Record initial Control and Power ERC reports and review
2026-10-28 Record preliminary power budget before schematic corrections
2026-10-28 Add high-load schematic candidate with CORE sense and revised N15 supply
2026-10-28 Select Samtec inter-board connectors and resolve analog VSS ERC warnings
2026-10-28 Distribute inter-board power across seven load zones and supervision
2026-10-28 Refresh task 1 and 2 documentation and distributed power budget
2026-10-30 Verify digital pin maps and move MCU SPI clock to FPGA SRCC; prepare MIG inputs
    MIRA-Digital-Patch: 73ac2f23a7d4a0d4119e0995085469fb50397bb688045691fe4033bcf7fa9ede
2026-10-30 MIRA.05: analog requirements and schematic fixes
2026-10-30 Review MIRA.06 components, connectors and assembly
2026-11-09 Add MIRA RevC KiCad projects and pre-layout review
